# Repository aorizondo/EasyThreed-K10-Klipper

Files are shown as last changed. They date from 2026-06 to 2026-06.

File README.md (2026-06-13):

# Frankenprinter — K10 + CNC → impresora/CNC multifunción con Klipper

Proyecto de fusión de una impresora **EasyThreed K10** con un **CNC cartesiano casero**
(Arduino Uno + CNC Shield, motores NEMA17, mecánica reciclada de impresoras Epson de cinta)
para construir una máquina multifunción gobernada por **Klipper** desde una **Raspberry Pi**.

> Estado: **fase de documentación y experimentación**. Este repo es la base de conocimiento
> y las configuraciones de partida, no un producto terminado.

## Idea de partida (la tuya)

- Reutilizar el **cabezal de la K10** (hotend, termistor, cartucho calefactor, motor de
  extrusión, fan) porque mecánicamente la K10 es limitada.
- Usar la **mecánica del CNC** (guías más precisas, mejores motores NEMA17, mayor volumen
  ~280×280×70 mm) para los ejes **X, Y, Z**.
- **Klipper en ambos MCU**, sincronizados por la Pi en modo **multi-MCU**:
  - **MCU CNC** (Arduino Uno + CNC Shield) → ejes X/Y/Z + endstops + sonda Z.
  - **MCU K10** (placa GD32F303) → extrusor + calefactor + termistor + fan.
- Añadir sensores extra (sonda de eje Z, etc.).

## ⚠️ Lee esto primero

Hay un hallazgo de la investigación que **cambia el plan**: el USB-C de la K10 es **solo
alimentación** (no datos), y la placa **no tiene chip USB-serie**. Habilitar Klipper en la
K10 implica **soldar UART directamente al MCU** y **reversear el pinout** (nadie lo ha
publicado). Es factible pero es ingeniería inversa, no "soldar un USB".

👉 Lee **[docs/00-RESUMEN-EJECUTIVO.md](docs/00-RESUMEN-EJECUTIVO.md)** antes de comprar o
soldar nada. Incluye una **matriz de decisión** entre el camino ambicioso (fiel a tu idea) y
una alternativa pragmática de menor riesgo.

## Índice de documentación

| Doc | Contenido |
|-----|---|
| [00 Resumen ejecutivo](docs/00-RESUMEN-EJECUTIVO.md) | Hallazgos críticos y matriz de decisión de arquitectura |
| [01 Arquitectura](docs/01-arquitectura.md) | Modelo multi-MCU de Klipper, roles, flujo de datos |
| [02 Hardware K10](docs/02-hardware-k10.md) | MCU GD32F303, USB-PD, drivers HR4988, MOSFET, SWD |
| [03 Hardware CNC](docs/03-hardware-cnc.md) | Arduino Uno + CNC Shield V3, A4988/DRV8825, NEMA17, mecánica Epson |
| [04 Soldadura UART K10](docs/04-soldadura-uart-k10.md) | La realidad del "USB", dónde soldar, técnica SMD |
| [05 Flasheo Klipper](docs/05-flasheo-klipper.md) | Compilar/flashear en ATmega328P y en GD32F303 |
| [06 Cableado y pinout](docs/06-cableado-pines.md) | Tablas de pines, conexiones físicas |
| [07 Instalación host](docs/07-instalacion-host-pi.md) | Raspberry Pi, KIAUH, Moonraker, Mainsail |
| [08 Calibración](docs/08-calibracion.md) | rotation_distance, PID, extrusor, input shaping |
| [09 Sensores y sonda Z](docs/09-sensores-zprobe.md) | BLTouch, inductiva, microswitch, piezo; bed mesh |
| [10 Reversing pinout K10](docs/10-reversing-pinout-k10.md) | Metodología para mapear los pines del GD32 |
| [99 BOM, riesgos, troubleshooting](docs/99-bom-riesgos-troubleshooting.md) | Compras, errores comunes y soluciones |

## Estructura del repo

```
3dprinter/
├── README.md                  ← este archivo
├── docs/                      ← documentación técnica (orden de lectura por número)
├── klipper-config/            ← configs Klipper de partida
│   ├── printer.cfg            ← config principal (incluye los módulos)
│   ├── include/               ← módulos: MCUs, steppers, extrusor, sonda, macros
│   └── moonraker.conf         ← config de Moonraker
├── diagrams/                  ← diagramas de arquitectura y pinout (Mermaid/ASCII)
├── repos/                     ← repos clonados (referencia y código)
│   ├── klipper/               ← firmware + host
│   ├── moonraker/             ← API server
│   ├── kiauh/                 ← instalador
│   ├── klipper-drawbot/       ← REFERENCIA: Klipper en Arduino Uno + CNC Shield V3
│   ├── ECF-Marlin/            ← REFERENCIA: Marlin comunitario para EasyThreed
│   └── EasyThreeD-K9-STM32/   ← REFERENCIA: firmware K9
└── reference/                 ← notas y fuentes externas guardadas
```

## Fuentes clave

- Klipper: <https://www.klipper3d.org/> · repo <https://github.com/Klipper3d/klipper>
- Reversing de la placa K10 (fuente técnica más completa):
  <https://palmarci.me/blog/2025-05-02-easythreed-k10-3d-printer-main-board-reversing/index.html>
- Klipper en Arduino Uno + CNC Shield (referencia directa):
  <https://github.com/gwisp2/klipper-drawbot>
- Hackaday K9 (identificación de MCU):
  <https://hackaday.com/2024/02/12/easythreed-k9-the-value-in-a-e72-aliexpress-fdm-3d-printer/>

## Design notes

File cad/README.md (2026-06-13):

# CAD — Enclosures modulares (OpenSCAD)

Cajas paramétricas para las placas de la frankenprinter. Diseñadas para **imprimir en la K9**
(volumen 100×100×100 mm, boquilla 0.4, **PETG sin cama caliente**), con **tapa atornillada M3**,
**ventiladores de PC estándar** y **acople modular entre cajas**.

## Estado

| Pieza | Estado | Notas |
|---|---|---|
| Librería `lib/enclosure_lib.scad` | ✅ | Caja, bosses M3, repisa + postes de retención, ventilador PC, puertos, acople |
| `k10_enclosure.scad` | ✅ | PCB 79×53 (fotogrametría), retención por contorno, 3 sockets, ventana botones. Falta solo confirmar altura de componentes con calibre |
| `arduino_cnc_enclosure.scad` | ✅ | Footprint Uno estándar, standoffs en agujeros oficiales, ventilador 50mm en tapa, COMP_H=40 para shield+drivers |
| Acople entre cajas | ✅ | Atornillado lateral M3 (`couple_holes`), altura/posiciones comunes; ver `coupling_demo.scad` |

### Sockets / puertos por caja
- **K10**: motores (atrás), mazo cabezal VIN/FAN/HE/TH (derecha), microSD+USB-C+DC (frente), ventilador 40mm (izquierda), ventana de botones (suelo).
- **Arduino+Shield**: USB-B/jack (izquierda), cables motores (derecha), endstops (atrás), ventilador 50mm (tapa).

### Acople entre cajas
Agujeros M3 pasantes a **z=30 mm** y **y=±24 mm** (constantes `COUPLE_Z`/`COUPLE_YS` en la lib), en pared maciza de todas las cajas. Dos cajas contiguas se unen con **tornillo M3 + tuerca**. Es encadenable (cualquier caja con cualquiera). `coupling_demo.scad` verifica la alineación.

## Cómo generar

```bash
cd cad
./build.sh                 # genera stl/*.stl + renders/*.png de todas las piezas
```
O manualmente una pieza:
```bash
openscad -D 'part="body"' -o salida.stl k10_enclosure.scad           # STL imprimible
xvfb-run -a openscad -D 'part="assembly"' -o vista.png \
   --imgsize=1100,800 --camera=0,0,0,55,0,30,250 k10_enclosure.scad  # preview
```
`part` puede ser `body`, `lid` o `assembly`.

## Verificar imprimibilidad

```bash
python3 -c "import trimesh;m=trimesh.load('stl/k10_body.stl');print(m.extents, m.is_watertight)"
```
Debe dar las 3 dimensiones < 100 mm y `True` (estanco). El build avisa si alguna pieza no es 2-manifold.

## Parámetros que debes medir (TODO-MEDIR)

En `k10_enclosure.scad`, ajústalos con calibre antes de imprimir en serio:

- `PCB_L`, `PCB_W`, `PCB_T` — contorno y grosor de la placa K10.
- `COMP_H` — altura del componente más alto (define el alto interior).
- `HOLE_INSET` / `HOLE_DX` / `HOLE_DY` — posición de los agujeros de montaje del PCB.
- Posición/tamaño de los **puertos** (`port_rect(...)`): USB-C, jack DC, mazo del cabezal, microSD.
  Mídelos respecto al borde y a la altura sobre el PCB.

## Convenciones de diseño

- **Tornillería M3**: pasante 3.4, autorroscante 2.7, inserto térmico 4.2 (en `lib`, ajustables).
- **Holgura FDM** (`FIT`) 0.30 mm — sube/baja según tu calibración PETG.
- **Pared** 2.4 mm, **suelo/tapa** 2.0–2.4 mm.
- **PETG sin cama caliente**: el suelo es una superficie grande → **usa brim/orejas** en el slicer para
  evitar warping; bed limpio + laca/barra de pegamento. Evita corrientes de aire (la propia carcasa ayuda).
- **Ventiladores**: tamaños estándar 40/50/60/80/92/120 con su separación de tornillos en `fan_hole_spacing()`.
  Un **40 mm** sobra para refrigerar los drivers y cabe de sobra en estas cajas.

## Estructura

```
cad/
├── lib/enclosure_lib.scad   # librería paramétrica (la base de todo)
├── k10_enclosure.scad       # caja de la placa K10
├── build.sh                 # genera stl/ + renders/
├── renders/                 # previews PNG (versionados, referencia visual)
└── stl/                     # STL generados (NO versionados; regenerar con build.sh)
```

## Acople entre cajas

La librería incluye `dovetail_male()` / `dovetail_slot()` (cola de milano) para que las cajas se
acoplen lateralmente sin tornillos extra (más una fijación M3 opcional). Falta integrarlo en cada caja
eligiendo en qué caras va el macho y en cuáles la hembra — siguiente iteración.

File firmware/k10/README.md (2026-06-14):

# Firmware Klipper para la EasyThreed K10

Compilación **en la nube** (GitHub Actions) de Klipper para la placa K10, evitando
necesitar el toolchain ARM en local.

## MCU y parámetros (verificados)

| Dato | Valor |
|---|---|
| MCU | **GD32F303CBT6** — LQFP48, 128 KB flash, 48 KB RAM, Cortex-M4 |
| Target Klipper | `STM32F103` (+ *Disable SWD* para clones GigaDevice) |
| Cristal | 8 MHz externo |
| Comunicación | USB nativo en **PA11 (D−) / PA12 (D+)** + pull-up 1.5 kΩ externa en D+ |
| Bootloader SD | escribe en **0x08004000** (offset `0x4000` = 16 KiB) |
| Fichero que busca el bootloader | **`p10_printer.bin`** (NO `mksLite.bin`, eso es la K9) |
| Señal de éxito | el bootloader renombra el fichero a `p10_printer.CUR` |

La configuración fuente está en [`klipper.config`](klipper.config) (fragmento mínimo;
el CI lo expande con `make olddefconfig`).

## Cómo obtener el firmware

1. En GitHub: pestaña **Actions** → **Build K10 Klipper firmware** → **Run workflow**.
2. Al terminar, descarga el artefacto **`p10_printer`** (contiene `p10_printer.bin`).

## Cómo flashear (microSD)

> ⚠️ Sin SWD no hay rescate. No sabemos si el cargador valida checksum/cabecera propia.
> El renombrado a `.CUR` es la señal de que lo aceptó.

1. Copia `p10_printer.bin` a la **raíz** de una microSD en **FAT32**.
2. Con la placa apagada, inserta la SD; enciende y espera ~10–30 s.
3. Reinserta la SD en el PC:
   - Si ahora se llama **`p10_printer.CUR`** → aceptado y escrito. ✅
   - Si **sigue** como `.bin` → rechazado (posible checksum/cabecera) → haría falta SWD.
4. Conecta el USB (PA11/PA12) al PC. Solo ahora debe aparecer
   `/dev/serial/by-id/usb-Klipper_stm32f103xe_*`.

Detalle del cableado USB y la pull-up: [`../../diagrams/k10-soldadura-usb.md`](../../diagrams/k10-soldadura-usb.md).

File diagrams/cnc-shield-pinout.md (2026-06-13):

# Diagrama — CNC Shield V3 (Arduino Uno) → pines Klipper

Verificado contra el fuente de GRBL (`cpu_map_atmega328p.h`) y `repos/klipper-drawbot`.
Correspondencia Arduino→ATmega:  **D0–D7 = PD0–PD7** · **D8–D13 = PB0–PB5** · **A0–A5 = PC0–PC5**.

---

## Fotos de referencia (montaje real Arduino Uno + CNC Shield + drivers)

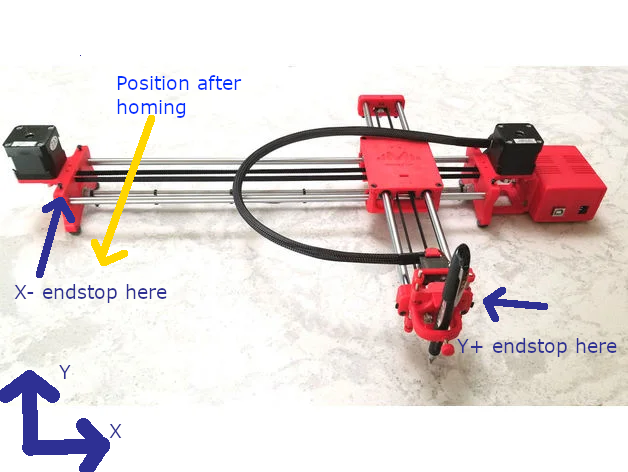
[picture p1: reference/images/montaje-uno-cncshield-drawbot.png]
Arduino Uno + CNC Shield V3 con drivers (montaje real, klipper-drawbot)


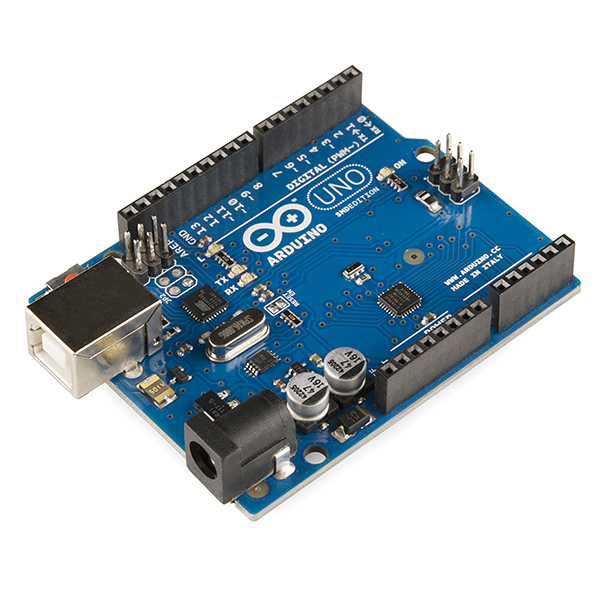
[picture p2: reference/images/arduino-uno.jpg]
Placa Arduino Uno R3


> Pinout gráfico oficial del CNC Shield V3 (no se puede incrustar por hotlink, ábrelo):
> Protoneer wiki <https://blog.protoneer.co.nz/arduino-cnc-shield/> ·
> Keyestudio <https://wiki.keyestudio.com/Ks0160_keyestudio_CNC_Shield_V3>

---

## Mapa de la shield (vista superior) — ASCII

```text
                        CNC SHIELD V3  (sobre Arduino Uno)
       +------------------------------------------------------------------+
       | ENABLE = D8 (PB0)  comun a los 4 drivers                         |
       |                                                                  |
       |   [ X ]        [ Y ]        [ Z ]        [ A ]                   |
       |   STEP = D2     STEP = D3    STEP = D4    (clon de X/Y/Z         |
       |   DIR  = D5     DIR  = D6    DIR  = D7     por jumpers, no usar) |
       |                                                                  |
       | Endstops:   X+ = D9 (PB1)    Y+ = D10 (PB2)    Z+ = D12 (PB4)    |
       | Spindle/servo: D11 (PB3, PWM HW)      SpinDir: D13 (PB5)         |
       | Abort A0 . Hold A1 . Resume A2 . Coolant A3                      |
       +------------------------------------------------------------------+
```

## Traducción a Klipper

```text
   stepper_x:   step=PD2   dir=PD5   enable=!PB0   endstop=^PB1
   stepper_y:   step=PD3   dir=PD6   enable=!PB0   endstop=^PB2
   stepper_z:   step=PD4   dir=PD7   enable=!PB0   endstop=^PB4   <-- PB4, no PB3
   (pin libre para sonda/servo: PB3 o PB5 si no usas spindle)
```

| Eje | STEP | DIR | ENABLE | ENDSTOP |
|-----|---|-----|---|---|
| X | PD2  | PD5 | !PB0 | ^PB1 (D9)  |
| Y | PD3  | PD6 | !PB0 | ^PB2 (D10) |
| Z | PD4  | PD7 | !PB0 | ^PB4 (D12) |

---

## Jumpers de microstepping (debajo de cada driver A4988/DRV8825)

```text
   MS1  MS2  MS3
    o    o    o     <- recomendado 1/16: los TRES jumpers PUESTOS (H H H en A4988)
                       NO uses 1/32 con el ATmega328P (riesgo "Timer too close").
```

| MS1 | MS2 | MS3 | A4988 | DRV8825 |
|-----|-----|-----|---|---|
| L | L | L | full  | full |
| H | H | H | 1/16  | 1/16 |
| L | L | H | 1/16  | 1/32 |

---

## Ajuste de corriente (Vref), medido con multímetro

```text
   A4988  (Rcs=0.1 ohm):   Vref = I_motor x 0.8     ej. 1.2 A -> 0.96 V
   DRV8825(Rcs=0.1 ohm):   Vref = I_motor / 2       ej. 1.2 A -> 0.60 V
   Mide entre el tornillo del potenciometro y GND. Apunta a ~70-85% de la I nominal del NEMA17.
```

## Aviso de ambiguedad del endstop Z

```text
   Shield V3 estandar (GRBL con VARIABLE_SPINDLE):  Z+ va a D12 = PB4.
   Si TU shield lleva Z+ a D11 -> seria PB3 (pero pierdes el pin PWM/servo).
   VERIFICA con multimetro a que pin del Arduino llega el header Z+/Z-.
```

Ref: [docs/03](../docs/03-hardware-cnc.md) ·
GRBL cpu_map <https://github.com/grbl/grbl/blob/master/grbl/cpu_map/cpu_map_atmega328p.h>

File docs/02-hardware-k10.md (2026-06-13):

# 02 — Hardware de la EasyThreed K10

Datos de ingeniería inversa publicada y de identificación de componentes. La fuente técnica más
completa es el reversing de palmarci.me; donde un dato no está verificado se indica.

Fuente principal: <https://palmarci.me/blog/2025-05-02-easythreed-k10-3d-printer-main-board-reversing/index.html>

---

## Microcontrolador

- **GigaDevice GD32F303RCT6**, núcleo ARM **Cortex-M4**.
- Encapsulado leído como **LQFP48** (nota: la referencia "RC" suele ser LQFP64/256 KB; posible
  discrepancia de lectura — verifícalo contando pines en tu placa).
- **Clon electrónico de STM32F103.** Para Klipper se compila como **STM32F103** y se trata como tal.
- Frecuencia/SRAM exactas de **esta** placa no confirmadas por la fuente (el GD32F303 de catálogo
  llega a 120 MHz). No son críticas para Klipper.

### Por qué importa
- **Klipper SÍ corre en GD32F303**, compilando con target STM32F103 + **bootloader de 28 KiB** y la
  opción *"Disable SWD at startup"*. Probado en miles de placas Creality 4.2.2.
  Ref: <https://klipper.discourse.group/t/installing-klipper-on-ender-3-4-2-2-board-and-gd32f303-chip/8165>

---

## Alimentación y "USB"

- Entrada por **DC barrel jack** + **USB-C**, con interruptor de 3 posiciones (OFF / USB-PD / DC).
- El **USB-C es SOLO alimentación**: controlador **PW6606 (USB-PD Sink)**. **No hay datos USB al MCU.**
- **No hay chip USB-serie** (CH340/CP2102). La operación de fábrica es **por microSD**.
- Hay una función USART0 en el firmware que **no se ejecuta**; los pines UART **no están ruteados** a
  ningún conector. → Para Klipper hay que **soldar UART al MCU** (ver [04](04-soldadura-uart-k10.md)).
- Tensión del sistema: el contexto apunta a **12 V** (no confirmado al 100% por la fuente). **Mídelo**
  antes de conectar nada: pon el multímetro en la entrada del barrel jack y en el riel principal.

> ⚠️ Antes de alimentar la K10 por DC mientras tienes el UART soldado y conectado a la Pi, asegúrate
> de **GND común** entre la K10 y la Pi/adaptador USB-TTL, y de **no** alimentar lógica de 5 V hacia
> pines de 3.3 V. El GD32 es de **3.3 V**: el adaptador USB-TTL debe ir en modo **3.3 V**, no 5 V.

---

## Drivers de motores

- **4× Heroic HR4988** (clon de A4988 con traductor integrado): X, Y, Z y extrusor.
- **Van soldados en la placa** (no son módulos extraíbles). No son TMC: **sin** StealthChop, **sin**
  UART, **sin** sensorless homing.
- En esta arquitectura solo usarás **el driver del extrusor** de la K10 (los de X/Y/Z los pone el
  CNC). Tendrás que localizar por reversing los pines step/dir/enable de **ese** driver.

---

## Calefactor y térmica

- MOSFET de potencia **Hooyi HY1403 (N-channel)** conmuta el cartucho calefactor del hotend.
  → El pin de **gate** de ese MOSFET es el `heater_pin` que buscas.
- **Termistor** NTC en divisor resistivo hacia un **pin ADC** del GD32 → ese es el `sensor_pin`.
  Tipo probable: NTC 100k. Verifica el `sensor_type` por calibración/medición (ver [08](08-calibracion.md)).
- Regulador **AMS1117** (genera el 3.3 V de la lógica).

---

## Depuración / flasheo (SWD)

Pines de debug accesibles (clave para reversing y para flashear Klipper sin bootloader SD):

| Señal | Pin GD32 |
|---|---|
| SWDIO | **PA13** |
| SWCLK | **PA14** |
| NRST  | **PB4**  |
| (JTAG extra) | PA15 / PB3 |

- En la unidad analizada la **RDP (read protection) estaba desactivada** → se puede volcar y reflashear.
- Puedes usar un **ST-Link V2** (~3€) o un **Raspberry Pi Pico como Picoprobe** + **OpenOCD**.
- Carga alternativa por **SD**: el bootloader MKS lee un `.bin` (la K10 carga `p10_printer.bin` a
  flash en offset `0x4000`, config en `k10_cfg.txt` offset `0x1F800`). Regla: el nombre del `.bin`
  debe acabar en `.bin` y **no** coincidir con el último flasheado, o el bootloader lo ignora.

---

## Firmware de fábrica

- **Marlin** (base 1.1.1 modificada por MKS, personalizada por EasyThreed). Las UIs EasyThreed están
  en Marlin mainline desde 2.0.9.3 (`MKS_ROBIN_LITE`).
- Para K10 se puede compilar Marlin con `BOARD_CREALITY_V422_GD32_MFL`.
- Proyecto comunitario Marlin para EasyThreed: **ECF-Marlin** (clonado en `repos/ECF-Marlin/`).
  Útil como **referencia de pinout** aunque sea para K7/K9.

---

## Lo que NO está publicado (lo tendrás que reversear tú)

- Pinout completo: qué pin del GD32 va a cada driver (step/dir/enable del extrusor), al gate del
  MOSFET del calefactor, al ADC del termistor, al fan y a los endstops.
- Metodología paso a paso en **[10 — Reversing del pinout K10](10-reversing-pinout-k10.md)**.

---

## Resumen para Klipper (Opción A)

| Recurso K10 | Uso en la frankenprinter | Pin Klipper |
|---|---|---|
| Driver extrusor (HR4988) | `[extruder]` step/dir/enable | `k10:P??` (reversing) |
| Gate MOSFET HY1403 | `[extruder] heater_pin` | `k10:P??` (reversing) |
| Divisor termistor → ADC | `[extruder] sensor_pin` | `k10:P??` (reversing) |
| Fan | `[fan]` / `[heater_fan]` | `k10:P??` (reversing) |
| UART soldado al MCU | enlace serie con la Pi | (define `serial:` en `[mcu k10]`) |

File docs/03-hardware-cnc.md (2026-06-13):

# 03 — Hardware del CNC (Arduino Uno + CNC Shield V3)

El CNC casero aporta la **mecánica** (ejes X/Y/Z) y el **MCU principal** de Klipper.

- Mecánica: cartesiana, piezas recicladas de impresoras Epson de cinta (correas timing, gargantas,
  deslizantes y carros). Dimensiones aprox. **280 × 280 × 70 mm** (X × Y × Z).
- Motores: **NEMA17** (paso 1.8° = 200 pasos/vuelta salvo que sean de 0.9°).
- Electrónica: **Arduino Uno (ATmega328P)** + **CNC Shield V3** con drivers **A4988/DRV8825**.
- Actualmente con **GRBL** → se reflashea a **Klipper**.

Referencia directa de este montaje exacto (Uno + CNC Shield V3 con Klipper):
`repos/klipper-drawbot/` y <https://github.com/gwisp2/klipper-drawbot>.

---

## Pinout CNC Shield V3 → nombres Klipper (VERIFICADO)

Correspondencia Arduino → puerto ATmega: **D0–D7 = PD0–PD7**, **D8–D13 = PB0–PB5**, **A0–A5 = PC0–PC5**.
Verificado contra el fuente de GRBL (`cpu_map_atmega328p.h`) y contra klipper-drawbot.

| Función | Pin Arduino | **Klipper** | Notas |
|---|---|---|---|
| X STEP | D2 | **PD2** | |
| Y STEP | D3 | **PD3** | |
| Z STEP | D4 | **PD4** | |
| X DIR | D5 | **PD5** | |
| Y DIR | D6 | **PD6** | |
| Z DIR | D7 | **PD7** | |
| ENABLE (común) | D8 | **!PB0** | activo-bajo (de ahí el `!`); deshabilita los 4 drivers a la vez |
| X endstop | D9 | **PB1** | usar `^PB1` (pull-up) |
| Y endstop | D10 | **PB2** | usar `^PB2` |
| Z endstop | **D12** | **PB4** | ver nota ⚠️ |
| Spindle Enable/PWM | D11 | PB3 | PWM por hardware; en drawbot lo usan para servo |
| Spindle Dir | D13 | PB5 | LED integrado del Uno |
| Coolant | A3 | PC3 | |
| Abort / Hold / Resume | A0 / A1 / A2 | PC0 / PC1 / PC2 | botones GRBL, no se usan en Klipper |

### ⚠️ Endstop Z = PB4 (D12), no PB3
La CNC Shield V3, compilada con `VARIABLE_SPINDLE` (el **default** de GRBL 0.9/1.1), mueve el PWM de
spindle a **D11 (PB3)** y por eso el **Z-limit queda en D12 (PB4)**. klipper-drawbot usa exactamente
`endstop_pin: ^PB4` para Z. **Verifícalo con multímetro**: comprueba a qué pin del Arduino llega el
header "Z+/Z−" de tu shield. Si en tu placa concreta Z va a D11, sería PB3 (pero entonces pierdes el
pin de servo/PWM). Recomendado: **cablea Z a D12 = PB4**.

### El "4º eje" (A) de la shield
En la CNC Shield V3 el slot **A** se **clona** de X/Y/Z por jumpers (no tiene pines step/dir propios
libres). No lo uses como eje independiente sin cablear a mano sacrificando otra función. Para esta
frankenprinter **no hace falta**: el extrusor lo mueve la K10, no la shield.

---

## Drivers A4988 / DRV8825

### Microstepping (jumpers MS1/MS2/MS3 bajo cada driver)
| MS1 | MS2 | MS3 | A4988 | DRV8825 |
|---|---|---|---|---|
| L | L | L | full | full |
| H | L | L | 1/2 | 1/2 |
| L | H | L | 1/4 | 1/4 |
| H | H | L | 1/8 | 1/8 |
| H | H | H | 1/16 | 1/16 |
| L | L | H | 1/16 | 1/32 |

**Recomendado: 1/16** (los 3 jumpers puestos en A4988). No subas a 1/32 con el ATmega328P: el límite
de step rate del AVR puede provocar `Timer too close`. En Klipper pon `microsteps: 16`.

### Corriente (Vref) — mide con el driver montado y alimentado
- **A4988** (Rcs=0.1Ω): `Vref = I_motor × 0.8`. Ej.: 1.2 A → 0.96 V. Ajusta a ~70–85 % de la nominal del motor.
- **DRV8825** (Rcs=0.1Ω): `Vref = I_motor / 2`. Ej.: 1.2 A → 0.6 V.
- Ojo con el resistor de sensado del módulo: "R100"=0.1Ω, "R050"=0.05Ω, "R200"=0.2Ω → cambia la fórmula.
- Mide Vref entre el **tornillo del potenciómetro** y **GND**. Empieza bajo y sube si pierde pasos; si
  el motor o el driver queman, baja.

---

## rotation_distance (cómo lo calcula Klipper)

Klipper **no usa steps/mm**; usa `rotation_distance` = mm que avanza el eje por **una vuelta** del motor.

```
rotation_distance = full_steps_per_rotation × microsteps / (steps_per_mm)
pasos/mm = (200 × microsteps) / rotation_distance         # 200 para NEMA17 1.8°
```

- **Correa GT2 (paso 2 mm) + polea N dientes:** `rotation_distance = 2 × N`. (20T → 40; 16T → 32.)
- **Husillo:** `rotation_distance = paso efectivo` (M5 → 0.8; T8 1 entrada → 2; T8 4 entradas → 8).

### Mecánica Epson reciclada: calíbrala, no la adivines
Las correas/poleas de impresoras Epson **no son estándar** (paso y nº de dientes inciertos). Pon un
valor de partida (p.ej. 40) y **calíbralo midiendo** con el procedimiento de "mover y medir" de
[08 — Calibración](08-calibracion.md). Para Z con husillo recuperado, mismo método en vertical con calibre.

> Pista: muchas correas de carro de Epson son de paso 2 mm; las poleas suelen rondar 16–22 dientes.
> Arranca con `rotation_distance: 40` en X/Y y ajusta tras medir 100–200 mm reales.

---

## Conexión al host

- **Uno genuino** (chip USB ATmega16U2) → `/dev/ttyACM0`.
- **Clon** (CH340) → `/dev/ttyUSB0`.
- Usa siempre el ID estable: `ls /dev/serial/by-id/*` y pon esa ruta en `serial:` del `[mcu]`.
- Si tienes varios CH340 sin serie única, usa `ls /dev/serial/by-path/*` y enchufa siempre en el mismo puerto.

---

## Límites reales del ATmega328P como MCU Klipper

- **Flash 32 KB**: justa → desactiva features en `make menuconfig` para que quepa.
- **RAM 2 KB**: ok para 3 ejes + endstops; no para muchos extras.
- **Step rate**: ~157k pasos/s con 1 stepper, **~99k con 3 simultáneos** (~33k/eje). Con 80 pasos/mm
  son ~410 mm/s teóricos por eje — de sobra para tu mecánica. Si aparece `Timer too close`: baja
  microsteps, velocidad o aceleración.
- **Una sola UART**, sin CAN. ENABLE compartido (no puedes deshabilitar ejes por separado).

Fuentes: <https://www.klipper3d.org/Benchmarks.html> ·
`repos/klipper-drawbot/README.md` ·
GRBL cpu_map: <https://github.com/grbl/grbl/blob/master/grbl/cpu_map/cpu_map_atmega328p.h>

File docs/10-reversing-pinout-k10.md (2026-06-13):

# 10 — Metodología para reversear el pinout de la K10

Esta es **la parte más dura** de la Opción A: nadie ha publicado qué pin del GD32F303 va a cada
actuador de la K10. Necesitas mapear, como mínimo:

- Driver del **extrusor** (HR4988): STEP, DIR, ENABLE.
- **Calefactor**: gate del MOSFET HY1403 (`heater_pin`).
- **Termistor**: pin ADC del divisor (`sensor_pin`).
- **Fan**: salida controlable.
- (Opcional) endstops, si quisieras usarlos — pero en esta arquitectura los pones en el CNC.

Tienes tres vías complementarias; combínalas. La 1 es la más rápida si funciona.

---

## Vía 1 — Extraer el pinout del firmware (la más eficiente)

El firmware de fábrica es **Marlin**, y Marlin define todos los pines en un archivo de placa. Si
identificas la placa Marlin que usa la K10, tienes el mapa casi regalado.

1. **Vuelca el firmware** de la K10 por SWD (RDP estaba desactivado en la unidad analizada):
   ```bash
   openocd -f interface/stlink.cfg -f target/stm32f1x.cfg \
           -c "init; reset halt; dump_image k10_original.bin 0x08000000 0x40000; exit"
   ```
   Guárdalo en `reference/`.
2. La K10 compila Marlin con un board tipo `BOARD_CREALITY_V422_GD32_MFL` (Creality 4.2.2 GD32). Abre
   el pins file correspondiente de Marlin y compáralo:
   - En `repos/ECF-Marlin/` (Marlin comunitario EasyThreed) busca los `pins_*.h` de la familia.
   - En Marlin mainline: `Marlin/src/pins/stm32f1/pins_CREALITY_V422.h` y la variante GD32.
   - Busca `HEATER_0_PIN`, `TEMP_0_PIN`, `E0_STEP_PIN`, `E0_DIR_PIN`, `E0_ENABLE_PIN`, `FAN_PIN`,
     `X/Y/Z` endstops.
3. **Traduce** los nombres Marlin (p.ej. `PB0`, `PA1`) directamente a Klipper (mismos nombres `Pxx`).
   ⚠️ Aviso: que la K10 sea "tipo 4.2.2" no garantiza pinout idéntico — EasyThreed pudo recablear. Por
   eso **verifica** cada pin con la Vía 2 antes de aplicar potencia.

> El blog de reversing (palmarci) ya confirma componentes (HR4988, MOSFET HY1403, AMS1117) y los pines
> SWD; úsalo como ancla. URL en [02](02-hardware-k10.md).

---

## Vía 2 — Trazado físico con multímetro (verificación, placa SIN alimentar)

Continuidad (modo pitido) entre el **pin del chip** y el **componente**:

- **Calefactor (`heater_pin`)**: localiza el MOSFET HY1403. Su **gate** va, normalmente vía una resistencia
  de puerta, a un pin del GD32. Pita entre cada pin candidato del MCU y el gate → ese es el `heater_pin`.
  (Source a GND, drain al conector del calefactor.)
- **Termistor (`sensor_pin`)**: localiza el conector del termistor y el divisor (una resistencia ~4.7k a
  3.3 V + el termistor a GND, nodo medio al ADC). Pita del nodo medio a un pin ADC del GD32 (PA0–PA7,
  PB0/PB1, PC0–PC5). Ese es el `sensor_pin`.
- **Driver extrusor (STEP/DIR/EN)**: identifica el HR4988 del extrusor. Sus pines STEP, DIR, ENABLE
  (según datasheet A4988/HR4988) se trazan a pines del GD32. Pita cada uno.
- **Fan**: igual que el calefactor pero el MOSFET/transistor del ventilador.

Anota todo en una tabla (plantilla abajo). Usa la datasheet del HR4988/A4988 para saber qué patilla es
STEP/DIR/EN, y un mapa de pines del GD32F303 LQFP para numerar patillas.

---

## Vía 3 — Sondeo dinámico con Klipper (confirmación final, con cuidado)

Una vez tengas Klipper en la K10 y candidatos del firmware/multímetro, **confirma** sin mecánica ni
calefactor conectados de potencia:

- **Salidas digitales** (heater gate, fan, enable): define un `[output_pin test]` temporal y conmútalo
  con `SET_PIN PIN=test VALUE=1/0` mientras mides con multímetro/LED en la salida. Verás qué conector se activa.
- **ADC (termistor)**: define el `[extruder] sensor_pin` candidato con `sensor_type: Generic 3950` y mira
  si lee temperatura ambiente coherente. Si lee 0 o max → pin equivocado.
- **STEP/DIR del extrusor**: con `STEPPER_BUZZ` (con el motor conectado pero el hotend frío y
  `min_extrude_temp` puenteado solo para test de movimiento — o usa un `[manual_stepper]` temporal).

> ⚠️ Haz el sondeo dinámico **con el calefactor de potencia desconectado** hasta confirmar el `heater_pin`.
> Activar por error un pin que no es el del MOSFET no rompe nada, pero activar el calefactor sin termistor
> validado sí es peligroso (térmica descontrolada). Klipper protege con `min_temp/max_temp`, pero valida
> el termistor **antes** de permitir calentar.

---

## Plantilla de mapa de pines (rellénala)

Copia esto a `reference/k10-pinmap.md` y ve completándolo:

```
# Mapa de pines K10 (GD32F303) — VERIFICAR cada uno antes de aplicar potencia

UART (comms host):   TX=PA9   RX=PA10   GND=___   [Vía: soldado, ver doc 04]

Extrusor STEP:   P____   [firmware:___ | multímetro:OK/NO | klipper:OK/NO]
Extrusor DIR:    P____   [ ... ]
Extrusor ENABLE: P____   (activo-bajo? sí/no -> usar ! )
Calefactor (heater_pin): P____   [gate MOSFET HY1403]
Termistor (sensor_pin):  P____   [ADC; sensor_type probado: __________]
Fan capa:        P____
Fan hotend:      P____   (si existe; o conéctalo a heater_fan)

Endstops (si se usaran en K10, NO recomendado): X=__ Y=__ Z=__
SWD: SWDIO=PA13  SWCLK=PA14  NRST=PB4   (confirmados por reversing publicado)
```

---

## Resultado

Cuando el mapa esté completo y verificado, traslada los valores a
`klipper-config/include/extruder-hotend.cfg` (reemplaza los `P??`). A partir de ahí, calibra térmica y
extrusor según [08](08-calibracion.md).

Si en algún punto te bloqueas (pin que no aparece, chip difícil de trazar), recuerda la salida de bajo
riesgo: **Opción B** ([00](00-RESUMEN-EJECUTIVO.md)) — un board barato con pinout conocido para el cabezal,
reutilizando el hotend/motor de la K10 como piezas.

Fuentes: reversing K10 <https://palmarci.me/blog/2025-05-02-easythreed-k10-3d-printer-main-board-reversing/index.html> ·
Marlin pins <https://github.com/MarlinFirmware/Marlin/tree/2.1.x/Marlin/src/pins/stm32f1> ·
`repos/ECF-Marlin/`

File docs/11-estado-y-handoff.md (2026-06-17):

# 11 · Estado del proyecto y handoff

> Documento vivo del **progreso real** (los docs 00–10 son el plan/diseño). Última actualización: 2026-06-16.
> Pensado para retomar el proyecto en una sesión limpia.

## Resumen en una línea

Frankenprinter: fusionar el **cabezal de una EasyThreed K10** + la **mecánica de un CNC casero**
(Arduino Uno + CNC Shield V3) bajo **Klipper multi-MCU** desde una Raspberry Pi. Repo público:
<https://github.com/aorizondo/EasyThreed-K10-Klipper>.

## Hardware confirmado (con correcciones al plan original)

| Componente | Dato confirmado |
|---|---|
| MCU K10 | **GD32F303CBT6** — LQFP48, **128 KB** flash, 48 KB RAM, Cortex-M4 (no el RCT6/64 que citaba palmarci) |
| Comunicación K10 | **USB nativo** PA11(D-)/PA12(D+) + pull-up 1.5 kΩ a 3.3 V soldada. Cristal 8 MHz |
| MCU CNC | **Arduino Uno R3 oficial** (2341:0043, ATmega16U2), ATmega328P @16 MHz |
| Drivers CNC | **4× A4988** (PCB roja "HW-134"), microstepping **1/16** (3 jumpers bajo cada driver) |
| Motores X/Y | Reciclados de impresoras **Epson LX** (pasos/correa a calibrar) |
| Motor 2º en Y | El eje Y tiene **2 motores** (pórtico). Socket A del shield, clonado de Y |
| Eje Z | Tornillo (≈ **M8**, paso por confirmar — probable varilla roscada 1.25 mm) |
| Área de trabajo | **380 × 360 mm** (X/Y) · **recorrido Z 40 mm** |
| Endstops | **Ninguno** en ningún eje → homing manual (cero a mano antes de cada trabajo) |

## Hitos conseguidos ✅

1. **K10 con Klipper por USB — FUNCIONANDO y validado.**
   - Compilado en GitHub Actions (`.github/workflows/build-k10-klipper.yml`), flasheado por microSD
     (`p10_printer.bin` → bootloader lo acepta y renombra a `.CUR`, offset 0x4000).
   - Enumera `1d50:614e`, comunica (console.py, get_uptime ok). CLOCK_FREQ=72 MHz.
   - `by-id`: `usb-Klipper_stm32f103xe_30303B4D1C20300836303638-if00`.
   - Config: [`firmware/k10/klipper.config`](../firmware/k10/klipper.config).
2. **Arduino (CNC) con Klipper — flasheado y validado** (con `HARD_PWM`). 14 KB/32 KB.
   - `by-id`: `usb-Arduino__www.arduino.cc__0043_7573530303135180C070-if00`. Serial 250000.
   - Config: [`firmware/cnc/klipper.config`](../firmware/cnc/klipper.config).
3. **Firmware OEM de fábrica de la K10 — respaldado** (billete de vuelta a fábrica).
   - Fuente: palmarci. `firmware/k10/stock/` (gitignorado, propietario) + README con hashes.
4. **Reversing del firmware OEM** ([`firmware/k10/reversing.md`](../firmware/k10/reversing.md)):
   - Steps/mm K10: X606 Y606 Z600 E1040; PID hotend Kp22.2/Ki1.08/Kd114; botones S3–S9.
   - Mapa de pines (38 agentes): PA2=termistor, PA3=endstop, PA5/6/7=SPI, teclado en PB*,
     PWM PB4/5/6/7/8. **Sin resolver: pin del HEATER** (soft-PWM vía tabla RAM) y eje de cada stepper.

## Decisiones de arquitectura

- **Reparto multi-MCU**: Arduino = movimiento X/Y/Z + endstops; K10 = cabezal (heater, fan, termistor,
  extrusor E). Pi = Klippy.
- **Doble motor Y en Klipper**: Opción B (software) → `[stepper_y]` + `[stepper_y1]` (socket A = D12/D13),
  sin auto-cuadrado (no hay endstops). Requiere quitar los jumpers de clonado del shield.
- **Sin endstops** → homing manual: `[force_move] enable_force_move: True` + macro `G28` con
  `SET_KINEMATIC_POSITION X=0 Y=0 Z=0`. (A4988 no soportan sensorless.)
- **PWM spindle/láser**: como D12/D13 se usan para el 2º motor Y, el PWM iría a D9/D10/D11 (libres al no
  haber endstops; son PWM HW del 328p).

## Próximos pasos para RETOMAR la vía Klipper

1. Confirmar con **multímetro** en la placa K10 real: pin del **heater**, pin del **termistor** (¿PA2?),
   y **qué eje es cada stepper** (el reversing no lo fija; además el binario es de otra variante de placa).
2. Calibrar **steps/mm** reales del CNC (motores Epson LX + tornillo Z) — ver más abajo.
3. Montar `printer.cfg` multi-MCU (lado CNC ya definido; lado K10 tras el multímetro).
4. Ajustar **Vref** de cada A4988 al energizar los NEMA/Epson.
5. Instalar host Klipper + Moonraker en la Pi (KIAUH).

## Estado actual: GIRO TEMPORAL A GRBL

El usuario vuelve **temporalmente a GRBL** en el Arduino+Shield para tener el CNC operativo como antes
(la vía Klipper queda documentada aquí para retomarla). Para GRBL:
- Los **jumpers de clonado del eje A se han vuelto a poner en Y** (modo espejo HW para el 2º motor Y).
- GRBL estándar (gnea/grbl 1.1) ve 3 ejes; el 2º motor Y lo mueve el hardware clonado. Pendiente:
  clonar/compilar/flashear GRBL (bloqueado por red en esta sesión) + configurar `$$` (ver plan GRBL).

## Punteros rápidos

- Toolchains locales: `avr-gcc`+`avrdude` (AVR) sí; `arm-none-eabi-gcc` NO (la K10 se compila por CI).
- venv para `console.py`: `repos/klipper/.venv-klippy` (Python 3.12 + pyserial/greenlet/cffi).
- Validar un MCU: `repos/klipper/.venv-klippy/bin/python repos/klipper/klippy/console.py [-b 250000] <dev>`.

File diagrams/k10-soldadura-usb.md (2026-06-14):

# Esquema de soldadura — USB nativo del GD32 (K10)

Opción **preferida** para comunicar la K10 con Klipper: usar el **USB nativo del GD32F303**
(PA11 = D−, PA12 = D+) llevándolo a un puerto/cable USB, con la **pull-up de 1.5 kΩ obligatoria
en D+**. La K10 aparecerá directamente como dispositivo Klipper (`/dev/serial/by-id/usb-Klipper_...`),
sin adaptador ni GPIO.

> Fuentes: Klipper sobre STM32F103 por USB
> <https://klipper.discourse.group/t/klipper-support-on-stm32f103-over-usb/25074> ·
> GD32F303 (Creality 4.2.2) <https://klipper.discourse.group/t/support-for-new-creality-boards-4-2-2-with-gd32f303/3016> ·
> El STM32F103/GD32F303 **no** trae pull-up interna en D+ → hay que añadirla externa.

---

## 1. Esquema eléctrico

```text
                     3.3 V
                       |
                  +----+----+
                  |  1.5 kΩ |   (pull-up OBLIGATORIA en D+; sin ella el USB NO enumera)
                  +----+----+
                       |
   GD32F303            |  nodo D+
   (placa K10)         |
   PA12  (USB D+) o----+--------------->  D+   (verde)   ----.
                                                              |
   PA11  (USB D-) o--------------------->  D-   (blanco)  ----+---> cable USB a la Raspberry Pi
                                                              |
   GND            o--------------------->  GND  (negro)   ----'
                                          VBUS +5V (rojo) = NO conectar al MCU
```

Notas eléctricas:
- **3.3 V para la pull-up**: tómalo del riel de 3.3 V de la placa (salida del **AMS1117**) o de un pin
  **VDD** del GD32. NO de 5 V.
- **VBUS (+5V, hilo rojo del USB): NO se conecta** al MCU. La K10 se alimenta por su propia DC; el USB
  solo aporta datos + masa.
- **GND común**: el hilo negro del USB une la masa de la K10 con la de la Pi (imprescindible).
- **D+ y D− cortos y trenzados** entre sí (son señal diferencial a 12 Mbit/s). Cuanto más cortos, mejor.
- Opcional pero recomendable: **22 Ω en serie** en cada línea D+/D− cerca del MCU (mejora integridad de
  señal). No es imprescindible para tramos cortos; la de **1.5 kΩ en D+ sí lo es**.

---

## 2. Localizar PA11 / PA12 en el chip

El reversing confirmó **SWDIO = PA13** y **SWCLK = PA14**. Usa SWDIO como referencia: los pines de USB
están justo al lado. Esta secuencia del borde es igual en LQFP48 y LQFP64 (solo cambia la numeración).

```text
   borde del GD32 (LQFP) — misma secuencia en 48 y 64 pines:
  +---++----++----++----++-----++---++---++-----++----+
   PA9  PA10  PA11  PA12   PA13  VSS  VDD   PA14  PA15 
  +---++----++----++----++-----++---++---++-----++----+
               D-    D+   SWDIO            SWCLK       

   Desde SWDIO (PA13), hacia el lado opuesto a VSS/VDD:
   PA13(SWDIO) -> PA12(D+) -> PA11(D-) -> PA10 -> PA9
```

Verifica SIEMPRE con multímetro (continuidad) antes de soldar: PA13 debe dar continuidad con el pad de
SWDIO que ya identificaste en el reversing; el contiguo es PA12 (D+).

> ⚠️ **Sobre la marca redonda (punto) del MCU:** ese punto marca el **pin 1 (VBAT)** y está en la
> esquina **DIAGONALMENTE OPUESTA** a PA11/PA12. Es normal que NO coincida con los pines que vas a
> soldar: D+/D− están en el lado contrario al punto. No es un error.
>
> En tu foto (punto arriba-izquierda, cristal a la izquierda) los pines de USB están en el **borde
> DERECHO**. Contando desde la esquina superior-derecha hacia abajo:
> **1 = VDD, 2 = VSS, 3 = PA13 (SWDIO), 4 = PA12 (D+), 5 = PA11 (D−).**

### Fotos de referencia
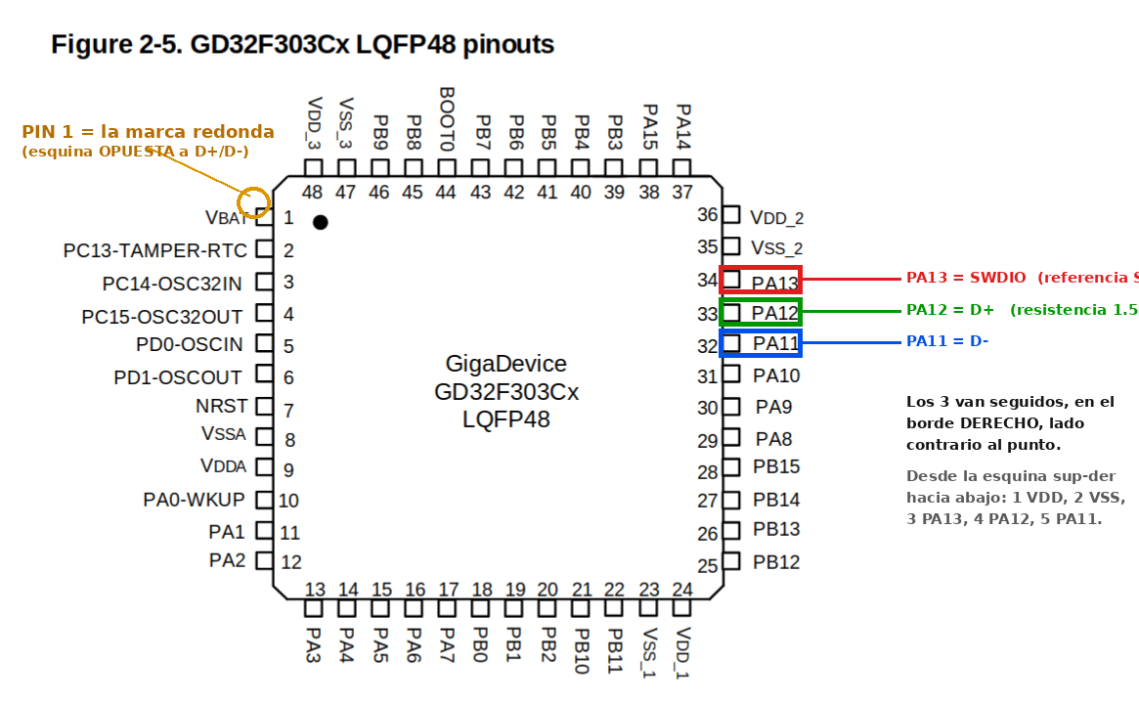
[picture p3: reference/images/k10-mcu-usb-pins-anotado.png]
Pines de USB anotados sobre el pinout: punto = pin 1 (esquina opuesta), PA13/PA12/PA11 en el borde derecho


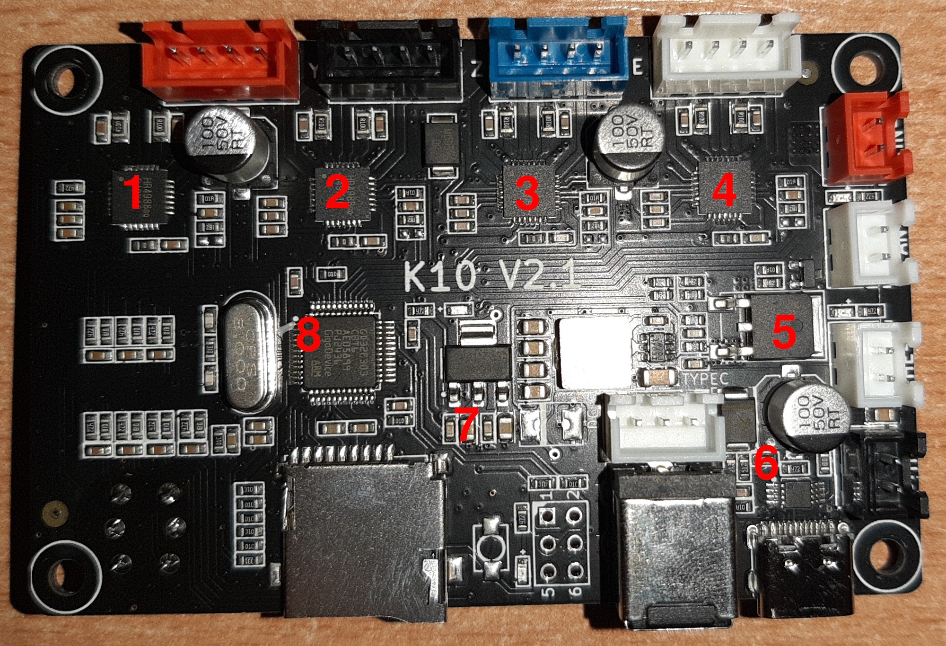
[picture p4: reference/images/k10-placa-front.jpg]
Cara de componentes de la K10 (MCU GD32 en el centro)


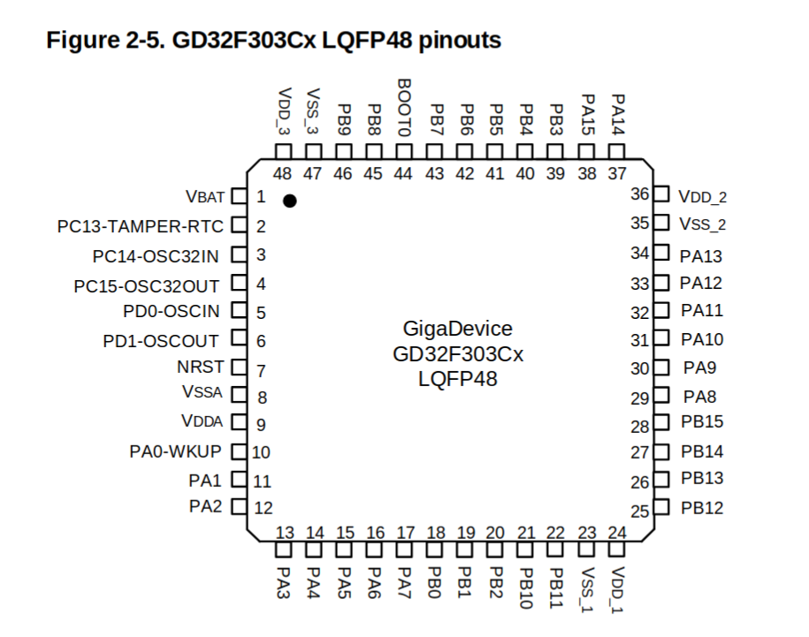
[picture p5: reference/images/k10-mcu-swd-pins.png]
Pines de depuración/SWD del GD32 identificados en el reversing


---

## 3. Colores estándar de un cable USB-A (al cortarlo)

| Hilo | Señal | Conecta a |
|---|---|---|
| Rojo  | VBUS +5V | **NO conectar** (la K10 se autoalimenta) |
| Blanco| D− | PA11 del GD32 |
| Verde | D+ | PA12 del GD32 (+ pull-up 1.5 kΩ a 3.3 V) |
| Negro | GND | GND de la K10 (masa común) |

> Si el cable no respeta colores, identifícalos con multímetro contra un conector USB-A conocido
> (pin 1=VBUS, 2=D−, 3=D+, 4=GND).

---

## 4. Procedimiento de soldadura

1. **Placa sin alimentar.** Pulsera antiestática.
2. Localiza y **verifica** PA12 (D+) y PA11 (D−) con multímetro (sección 2).
3. Suelda la **pull-up de 1.5 kΩ** entre PA12 (D+) y el riel de 3.3 V (salida AMS1117 o VDD). Es el
   punto crítico.
4. Suelda hilos finos (AWG30) a PA12 (D+) y PA11 (D−), **cortos y trenzados** entre sí.
5. Suelda GND a un punto de masa cómodo.
6. Conecta esos hilos a los del cable USB: verde→D+, blanco→D−, negro→GND. **Rojo (VBUS) aislado.**
7. Fija todo con kapton/pegamento (alivio de tensión).
8. Enchufa el USB a la Pi y alimenta la K10 por su DC.
9. En la Pi: `ls /dev/serial/by-id/*` → debe aparecer `usb-Klipper_stm32f103xe_...` (tras flashear Klipper).

---

## 5. Klipper para esta opción (menuconfig)

```text
Micro-controller Architecture: STMicroelectronics STM32
Processor model: STM32F103
Bootloader offset: 16KiB bootloader     (K10: el cargador escribe en 0x4000 = 16 KiB; "No bootloader" si flasheas por SWD)
Communication interface: USB (on PA11/PA12)      <-- ESTA es la clave de la opción USB nativo
[*] Disable SWD at startup (GD32)
```

Tras `make`, flashea por SWD o SD (ver [docs/05](../docs/05-flasheo-klipper.md)). En `[mcu k10]`:
`serial: /dev/serial/by-id/usb-Klipper_stm32f103xe_XXXX-if00`.

> ⚠️ **Importante — el USB nativo NO enumera hasta que Klipper esté flasheado.** El periférico USB del
> GD32 lo activa el *firmware*; no es un chip USB-serie autónomo (CH340/FT232). Con el firmware de
> fábrica (EasyThreed), conectar el cable a la PC no produce **nada** (ni "dispositivo desconocido").
> Por eso el **primer** flasheo debe ir por **SWD o microSD**, nunca por USB. Solo después de tener
> Klipper dentro aparecerá `/dev/serial/by-id/usb-Klipper_...` y servirá para validar esta soldadura.

---

## 6. Flasheo por microSD (datos reales del bootloader de la K10)

> Fuente: reversing de la placa K10 (palmarci)
> <https://palmarci.me/blog/2025-05-02-easythreed-k10-3d-printer-main-board-reversing/index.html>

La K10 **NO** usa el bootloader MKS de la K9. No busca `mksLite.bin`. Su cargador propio busca:

| Dato | Valor en la K10 |
|---|---|
| MCU | **GD32F303CBT6** (Cortex-M4, **LQFP48**, 128 KB flash, 48 KB RAM) — confirmado por el marcado del chip; el reversing de palmarci citaba un RCT6/LQFP64, pero esta placa monta el CBT6 de 48 pines |
| Fichero de firmware que busca en la raíz de la SD | **`p10_printer.bin`** |
| Offset de escritura | **`0x4000` = 16 KiB** (→ menuconfig: *16KiB bootloader*) |
| Fichero de config opcional | `k10_cfg.txt` (se almacena en `0x1F800`) |
| Tras flasheo correcto | renombra el `.bin` a `.CUR` |

Procedimiento:

1. **Respalda primero el firmware de fábrica** (por SWD, leyendo la flash) y guárdalo. Plan de
   recuperación imprescindible por si el `.bin` de Klipper no bootea.
2. Compila Klipper con el menuconfig de la sección 5 (**offset 16KiB**).
3. Copia `out/klipper.bin` a la **raíz** de una microSD (FAT32) **renombrado a `p10_printer.bin`**.
4. Con la placa apagada, inserta la SD; enciende y espera ~10-30 s.
5. Reinserta la SD en la PC: si el fichero ahora se llama `p10_printer.CUR`, el cargador lo aceptó y
   escribió. Si **sigue** llamándose `.bin`, fue **rechazado** (posible checksum/header propio del
   cargador) → habrá que flashear por SWD.

> ⚠️ **Sin confirmar:** no sabemos si el cargador de la K10 valida checksum/cabecera o desencripta el
> `.bin` (muchos cargadores tipo MKS sí lo hacen). Por eso el paso 1 (respaldo + SWD de rescate) no es
> opcional. La señal de éxito/rechazo es el renombrado a `.CUR` del paso 5.

---

## Comparativa rápida con las otras vías

| Vía | Soldadura | Compras | Resultado |
|---|---|---|---|
| **A. USB nativo** | PA11/PA12 + R 1.5 kΩ + cable USB | nada (cable USB) | `/dev/serial/by-id/usb-Klipper_...` |
| B. UART por GPIO Pi | PA9/PA10/GND a GPIO de la Pi | nada | `/dev/ttyAMA0` |
| C. UART + USB-TTL | PA9/PA10/GND al adaptador | adaptador 3.3 V | `/dev/serial/by-id/...` |

Las tres valen. La **A** es la más "limpia" (USB de verdad) y es la que sugeriste; su único extra es la
resistencia de 1.5 kΩ. Si soldar D+/D− finos te incomoda, la **B** (UART al GPIO de la Pi) es el plan B
sin comprar nada. Ver [k10-uart-conexion.md](k10-uart-conexion.md).

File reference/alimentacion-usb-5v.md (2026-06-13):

# Alimentar el MCU de la K10 por un USB independiente (5V) con protección

Objetivo: un **puerto USB separado** (no el USB-C PD de fábrica) que alimente **solo la lógica
del MCU** (3.3V) y, opcionalmente, lleve los datos de Klipper (D+/D-). Los motores y el
calefactor siguen necesitando 12V aparte; el USB **no** los alimenta.

## Dónde inyectar los 5V: la entrada del AMS1117 (VIN)

La K10 genera su 3.3V con el regulador **AMS1117-3.3** (12V → buck → ~5V → AMS1117 → 3.3V → MCU).
Para alimentar la lógica con 5V del USB, se inyecta en la **entrada del AMS1117 (pin VIN)**, que es
el carril de ~5V. **No** se toca el USB-C PD ni los pads "DC PWR/TYPEC PWR" (esos son de 12V).

### Identificar el pin VIN del AMS1117 (encapsulado SOT-223, 3 patillas + lengüeta)
| Patilla | Función | Cómo reconocerla |
|---|---|---|
| Lengüeta grande + patilla central | **VOUT = 3.3V** | mide 3.3V a masa con la placa encendida → NO soldar aquí |
| Una patilla lateral | **GND** | mide 0V |
| La otra patilla lateral | **VIN** (entrada) | mide ~5V (o ~12V si va directo) → **AQUÍ van los 5V+** |

> Con la placa alimentada normalmente, mide cada patilla a masa con el multímetro: la de 3.3V es la
> salida (no tocar), la de 0V es GND, y la restante es **VIN** (ahí soldar el 5V+ del USB).
> El AMS1117 tolera de ~4.5V a ~15V en VIN, así que 5V es seguro.

## Protección recomendada (tu pregunta de seguridad) — SÍ, es posible y aconsejable

El **AMS1117 ya es el regulador** que protege la lógica (salida 3.3V estable). Lo que hay que
proteger es la **entrada de 5V**. Cadena recomendada, sencilla y robusta:

```text
  USB 5V+ ──[ Polyfuse 500mA ]──►|──────┬──────────────►  AMS1117 VIN  ──►(regula a 3.3V → MCU)
                              Schottky   │
                              (SS14 /    ├─[ TVS 5.6V ]─┐   (opcional, anti-picos/ESD)
                               1N5819)   ├─[ 10µF ]─────┤   (estabiliza la entrada)
                                         │              │
  USB GND ───────────────────────────────┴──────────────┴──────────────►  GND de la placa
```

- **Polyfuse (PTC) 500 mA**: rearmable; protege contra **cortocircuito / sobrecorriente**.
- **Diodo Schottky (SS14 o 1N5819)**, cátodo hacia la placa: **anti-polaridad inversa** y evita
  retroalimentar si algún día también conectas los 12V. Caída baja (~0.2–0.3V a esta corriente).
- **TVS 5.6V (SMAJ6.0A)** a masa: recorta **sobretensiones/picos** (opcional pero recomendable).
- **Condensador 10µF** a masa: estabiliza la entrada.

Caída total: 5V − polyfuse(~0.1) − Schottky(~0.25) ≈ **4.6V** en VIN → el AMS1117 da 3.3V de sobra
(la lógica consume <100 mA). Mantén el cable corto para no perder más tensión.

### Alternativa "todo en uno"
Un **módulo de protección USB** (sobretensión + sobrecorriente, los venden baratos) intercalado entre
el USB y el VIN del AMS1117 hace lo mismo sin montar componentes sueltos.

## Cableado completo del USB independiente (datos + alimentación)

Un solo conector USB hacia la Pi → alimenta la lógica **y** lleva Klipper por USB:

| Hilo USB | Va a | Notas |
|---|---|---|
| **5V+ (rojo)** | AMS1117 **VIN** (con la protección de arriba) | alimenta la lógica 3.3V |
| **D+ (verde)** | MCU **PA12** + **pull-up 1.5kΩ a 3.3V** | datos USB Klipper |
| **D- (blanco)** | MCU **PA11** | datos USB Klipper |
| **GND (negro)** | masa de la placa | común |

> PA11/PA12 están **contiguos a SWDIO (PA13)**, que el reversing identificó. Ver
> [diagrams/k10-soldadura-usb.md](../diagrams/k10-soldadura-usb.md) para localizarlos y la pull-up.
> Guía visual de puntos: [reference/images/k10-usb-solder-guide.jpg](images/k10-usb-solder-guide.jpg).

## Seguridad importante
- Esto alimenta **solo la lógica**. El **calefactor NO** debe activarse sin termistor validado y sin
  los 12V; Klipper lo protege, pero no fuerces calentamiento con USB.
- No intentes mover motores ni calentar desde los 5V del USB (no hay corriente para eso).
- GND **común** entre USB/Pi y placa. Señales a 3.3V hacia el MCU (D+/D-).

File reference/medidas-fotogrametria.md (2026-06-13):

# Medidas de la placa K10 por fotogrametría

Como no hay cotas publicadas del PCB de la K10, se estimaron a partir de las fotos cenitales del
reversing usando un **componente de tamaño estándar como regla**. Método reproducible con
`reference/images/` + OpenCV (scripts ad-hoc).

## Método

1. **Referencia de escala = encapsulado del MCU.** El chip se lee como **GD32F303 (GigaDevice, ARM)**.
   Se contaron los pines por lado mediante perfil de intensidad: **~12 pines/lado → LQFP48**
   (no LQFP64). El LQFP48 tiene **cuerpo de 7.0 mm** (lead-span 9.0 mm).
2. Medido el cuerpo del MCU en la foto frontal: **≈167 px** → escala **0.0419 mm/px**
   (cross-check con lead-span 9 mm ≈ 220 px → 0.0409 mm/px; coinciden en ~0.041).
3. Contorno del PCB por perfiles de brillo (placa oscura sobre fondo claro), en ambas caras.

## Resultados

| Magnitud | Valor | Confianza | Notas |
|---|---|---|---|
| **Contorno PCB** | **79 × 53 mm** | Alta (±2 mm) | Aspecto 1.50 coincide por las dos caras |
| Grosor PCB | 1.6 mm | Asumido | estándar de industria |
| Patrón de agujeros (4 esquinas) | ~72 × 44 mm centro-a-centro | Media (±2-3 mm) | esquinas inferiores ruidosas (QR/botón) |
| Inset de agujeros desde borde | ~3.5 × 4.5 mm | Media | derivado del patrón |
| **Altura de componentes** | **NO medible** | — | las fotos cenitales no dan altura; usar calibre |

## Escala — verificación cruzada

- Frontal: 1881 × 1258 px × 0.0419 = **78.8 × 52.7 mm** (aspecto 1.495).
- Trasera: 1882 × 1191 px (aspecto 1.580; ligero escorzo vertical o sobresale el botón redondo).
- Ambas dan ~79 mm de ancho → el contorno es robusto.

## Implicación de diseño

- El **contorno (79×53)** es fiable → la caja se dimensiona con seguridad.
- El **patrón de agujeros** NO es lo bastante preciso para alinear standoffs a ciegas.
  → La caja debe **retener el PCB por su contorno** (repisa perimetral + presión de la tapa),
  usando los standoffs solo como apoyo aproximado. Verificar los 4 agujeros con calibre antes de
  fijar tornillos de PCB.
- **COMP_H (altura)**: medir con calibre el componente más alto (condensadores/conectores). Solo
  afecta al alto de la caja, que lleva margen; valor provisional 17 mm.

## Layout de puertos por borde (verificado en fotos)

- Borde con 4 conectores de motor (X/Y/Z/E) | jack DC 12V + USB-C | mazo del cabezal (HE+TH+FAN) |
  ranura microSD | botones del reverso (S3 Retract, S4 Feed, S5 ▲ Print, S6-S9 niveles).

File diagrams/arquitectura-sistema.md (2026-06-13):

# Diagrama — Arquitectura del sistema

## Vista lógica (multi-MCU Klipper)

```mermaid
graph TD
    subgraph PI["Raspberry Pi (host)"]
        K["Klipper host<br/>(cinemática, look-ahead,<br/>input shaping, PID)"]
        M["Moonraker (API)"]
        W["Mainsail / Fluidd (web)"]
        W --> M --> K
    end

    K -- "USB serie<br/>/dev/serial/by-id" --> CNC
    K -- "USB serie<br/>(adaptador USB-TTL)" --> K10

    subgraph CNC["MCU 'cnc' — Arduino Uno (ATmega328P) + CNC Shield V3"]
        X["Stepper X + endstop"]
        Y["Stepper Y + endstop"]
        Z["Stepper Z + endstop"]
        P["Sonda Z (opcional)"]
    end

    subgraph K10["MCU 'k10' — placa GD32F303 (cabezal)"]
        E["Extrusor (stepper)"]
        H["Calefactor (MOSFET HY1403)"]
        T["Termistor (ADC)"]
        F["Fan"]
    end

    CNC --> MEC["Mecánica Epson reciclada<br/>NEMA17 · ~280x280x70 mm"]
    K10 --> HEAD["Cabezal K10<br/>hotend + extrusor"]
```

## Vista física (alimentación y masas)

```
   Fuente potencia (12-24V) ──► CNC Shield ──► motores NEMA17 (XYZ)
   Fuente K10 (~12V)        ──► placa K10  ──► calefactor + extrusor
   Fuente 5V/3A             ──► Raspberry Pi
                                  │
                                  ├─USB─► Arduino Uno (lógica + CNC Shield)
                                  └─USB─► adaptador USB-TTL ─UART(3.3V)─► GD32 K10

   ⚠️ TODAS las masas (GND) unidas. Señales al GD32 a 3.3V. Ver docs/06.
```

> Opción B/C: el bloque "MCU k10" se sustituye por un board de impresora con pinout conocido
> (sin reversing ni soldadura SMD). La topología lógica es idéntica.

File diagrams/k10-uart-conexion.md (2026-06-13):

# Diagrama — Comunicación de la K10 con el host (3 vías)

La K10 **no tiene USB de datos de fábrica** (su USB-C es solo alimentación, USB-PD). Hay **tres**
formas de darle a Klipper un enlace con la K10. Todas trabajan a **3.3 V** (nivel del GD32).

- **A. USB nativo del GD32** (recomendada) — PA11/PA12 + pull-up 1.5 kΩ → cable USB. Aparece como
  dispositivo Klipper por USB. **Esquema de soldadura completo:** [k10-soldadura-usb.md](k10-soldadura-usb.md).
- **B. UART por GPIO de la Raspberry Pi** — sin comprar nada, 3 cables a la cabecera de la Pi.
- **C. UART + adaptador USB-TTL** — si prefieres por USB y ya tienes un adaptador 3.3 V.

> No necesitas comprar adaptador: con la **A** (cable USB) o la **B** (GPIO de la Pi) te apañas con lo
> que ya tienes. Detalle y seguridad en [docs/04](../docs/04-soldadura-uart-k10.md).

---

## Fotos reales de la placa (K10 V2.1)

Placa K10 V2.1 - cara de componentes (MCU GD32 en el centro)

`1-4` = drivers **HR4988** (X/Y/Z/E) · MCU **GD32F303RCT6** (centro) · MOSFET calefactor **HY1403** ·
regulador **AMS1117** · controlador **PW6606** (USB-PD).

Cableado de la K10 en su carcasa

---

## A. USB nativo del GD32 (recomendada — la opción que propusiste)

PA12 = USB D+, PA11 = USB D−. Necesita **1.5 kΩ de D+ a 3.3 V**. Ver el esquema eléctrico de soldadura
completo en **[k10-soldadura-usb.md](k10-soldadura-usb.md)**. Esquema lógico:

```text
     PLACA K10 (GD32F303)         RASPBERRY PI
    +----------------+        +------------------+
    |                |        |                  |
    | PA12 D+  o     |--------| o  D+   (USB)    |
    | PA11 D-  o     |--------| o  D-   (USB)    |
    | GND      o     |--------| o  GND           |
    |                |        |                  |
    +----------------+        +------------------+
     (+ pull-up 1.5 kΩ de PA12/D+ a 3.3 V — OBLIGATORIA)
     VBUS +5V del USB: NO conectar al MCU.  D+/D- cortos y trenzados.
```

Klipper: interfaz de comunicación **USB (PA11/PA12)**. Resultado: `/dev/serial/by-id/usb-Klipper_stm32f103xe_...`.

---

## B. UART por GPIO de la Raspberry Pi (sin comprar nada)

```text
    PLACA K10 (GD32F303, 3.3 V)            RASPBERRY PI  (cabecera GPIO, 3.3 V)
    +------------------------+            +------------------------------------+
    |                        |   cable A  |                                    |
    |   USART1 TX = PA9   o--|----------->|--o RXD = GPIO15   (pin fisico 10)  |
    |                        |   cable B  |                                    |
    |   USART1 RX = PA10  o--|<-----------|--o TXD = GPIO14   (pin fisico 8)   |
    |                        |   cable C  |                                    |
    |   GND               o--|------------|--o GND            (pin fisico 6)   |
    |                        |            |                                    |
    +------------------------+            +------------------------------------+

    Regla: TX de un lado --> RX del otro (cruzado). Si no conecta, intercambia A y B.
```

En la Pi: `sudo raspi-config` → Serial → consola por serie **NO**, hardware serial **SÍ**.
Klipper: comunicación **Serial (USART1, PA9/PA10)**. En `[mcu k10]`: `serial: /dev/ttyAMA0`.

---

## C. UART + adaptador USB-TTL (3.3 V)

```text
     PLACA K10 (3.3 V)         ADAPTADOR USB-TTL (3.3 V)
    +----------------+        +----------------------+
    |                |        |                      |
    | TX = PA9   o   |------->| o  RX                |
    | RX = PA10  o   |<-------| o  TX                |
    | GND        o   |--------| o  GND               |
    |                |        | VCC 3.3 V (NO usar)  |
    |                |        |                      |
    +----------------+        +----------------------+
              (el adaptador va por USB a la Pi)
```

Mismo cruce TX↔RX, GND común, VCC del adaptador sin conectar. Adaptador **en 3.3 V** (5 V daña el GD32).

---

## SWD — para flashear / volcar firmware (no es la comunicación de Klipper)

```text
    GD32 K10:   SWDIO = PA13     SWCLK = PA14     NRST = PB4     (+ GND y 3.3 V)

    Programador:  ST-Link V2     o     Raspberry Pi Pico (Picoprobe) + OpenOCD
```

Pines SWD del GD32 en la K10

Montaje de depuración SWD sobre la K10

---

## Tabla resumen de cableado

| Señal | Pin K10 (GD32) | Opción A — USB nativo | Opción B — Pi GPIO | Opción C — USB-TTL  |
|---|---|---|---|---|
| D+ / TX | PA12 (D+) / PA9 (TX)  | PA12 → D+ del cable USB | — | — |
| D- / RX | PA11 (D-) / PA10 (RX) | PA11 → D- del cable USB | — | — |
| Pull-up | — | 1.5 kΩ de PA12 a 3.3 V  | no aplica | no aplica |
| TX (UART) | PA9 | — | → RXD GPIO15 (pin 10) | → RX del adaptador  |
| RX (UART) | PA10 | — | → TXD GPIO14 (pin 8)  | → TX del adaptador  |
| GND | GND | → GND del USB | → GND (pin 6) | → GND del adaptador |

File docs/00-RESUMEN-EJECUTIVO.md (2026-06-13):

# 00 — Resumen ejecutivo y matriz de decisión

Lee esto antes de comprar o soldar nada. Resume los hallazgos de la investigación técnica y
te plantea la decisión de arquitectura que condiciona todo lo demás.

---

## Hallazgos críticos (verificados)

### 1. La K10 es el chip correcto para Klipper, la K9 no
| Impresora | MCU | ¿Klipper? |
|---|-----|---|
| **K10** | **GigaDevice GD32F303RCT6** (Cortex-M4) | ✅ **Sí** — se compila como STM32F103 + bootloader 28 KiB |
| K9 | ARERY **AT32F403ARCT7** (clon STM32F1, Artery) | ❌ No soportado por Klipper |

Sacrificar la K10 y conservar la K9 (que dominas) es, por casualidad, la decisión correcta:
el GD32 de la K10 **sí** corre Klipper; el Artery de la K9 **no**.
Fuente: [reversing K10](https://palmarci.me/blog/2025-05-02-easythreed-k10-3d-printer-main-board-reversing/index.html),
[Hackaday K9](https://hackaday.com/2024/02/12/easythreed-k9-the-value-in-a-e72-aliexpress-fdm-3d-printer/),
[Klipper en GD32F303](https://klipper.discourse.group/t/installing-klipper-on-ender-3-4-2-2-board-and-gd32f303-chip/8165).

### 2. "Soldar el USB de la K10" NO funciona como esperas
- El **USB-C de la K10 es solo alimentación (USB-PD)**: va a un controlador PD (PW6606), **no al MCU**.
- **No hay chip USB-serie** (CH340/CP2102). De fábrica se opera **solo por microSD**.
- Klipper necesita un enlace serie/USB permanente con el host. Para tenerlo en la K10 hay que
  **soldar 3 cables (TX, RX, GND) directamente a pines USART del GD32** (paso 0.5 mm) y conectar
  un **adaptador USB-TTL** (FTDI/CP2102/CH340) hacia la Pi. Ver [04](04-soldadura-uart-k10.md).

### 3. El verdadero coste de la K10 es reversear el pinout
- **Nadie ha publicado** el pinout completo de la K10 ni un `printer.cfg`.
- Tendrás que mapear qué pin del GD32 va a: cada driver HR4988 (step/dir/enable), el MOSFET del
  calefactor, el ADC del termistor, el fan y los endstops. Metodología en [10](10-reversing-pinout-k10.md).
- Tienes a favor: **SWD accesible** (PA13/PA14/NRST), RDP desactivado en la unidad analizada, y un
  **volcado de firmware** público del que extraer pistas.

### 4. El Arduino Uno como MCU de Klipper: viable pero justo
- ATmega328P **sí** está soportado (16 MHz). Referencia directa: [klipper-drawbot](https://github.com/gwisp2/klipper-drawbot) (Uno + CNC Shield V3).
- Límites reales: **flash 32 KB** (hay que desactivar features en menuconfig), **~99k pasos/s con 3 ejes
  simultáneos**, riesgo de `Timer too close` si abusas de microstepping. Quédate en **1/16**.

### 5. Volumen real de la K10
La cama original de la K10 es **100×100×100 mm**. La ganancia de tu CNC (~280×280×70 mm en XY,
menos en Z) es enorme para X/Y, pero **el Z de ~70 mm es bajo** para una impresora — tenlo en cuenta
al diseñar la bancada/portaboquilla. Ver [03](03-hardware-cnc.md).

---

## Matriz de decisión de arquitectura

Tres caminos para gobernar el **cabezal** (hotend + extrusor + termistor + fan). El CNC siempre
hace X/Y/Z con el Arduino+Klipper; lo que cambia es **quién controla el cabezal**.

| | **A — Klipper en la K10** (fiel a tu idea) | **B — Placa dedicada** (pragmático) | **C — Todo en una placa** (máxima simplicidad) |
|---|---|---|---|
| Cabezal lo controla | Placa K10 con Klipper (toolhead MCU) | Una placa barata Klipper-friendly (SKR Mini / MKS / Ender 4.2.2 GD32) | Esa misma placa controla **también** X/Y/Z |
| Arduino+CNC Shield | XYZ | XYZ | Se jubila (o queda de repuesto) |
| Reutiliza la K10 | ✅ Sí (su gracia) | ❌ Solo el hotend/motor como piezas sueltas | ❌ |
| Soldadura SMD en MCU | ✅ Necesaria (UART al GD32) | ❌ No | ❌ No |
| Reversing de pinout | ✅ Necesario (lo más duro) | ❌ No | ❌ No |
| Multi-MCU | Sí (2 MCU) | Sí (2 MCU) | No (1 MCU) |
| Coste € | ~0 (reusas) + adaptador USB-TTL (~3€) | +15–25€ (placa) | +25–40€ (placa con drivers para 4–5 motores) |
| Dificultad | Alta (reversing + microsoldadura) | Media | Baja |
| Riesgo de bloqueo | Alto (pinout desconocido) | Bajo | Muy bajo |
| Valor "maker"/aprendizaje | Máximo | Medio | Bajo |

### Recomendación honesta
- Si esto es un **reto de ingeniería** y disfrutas reverseando: **Opción A**. Toda la documentación
  está preparada para ella (es el "camino principal" del repo). Empieza por validar comms y pinout
  ([10](10-reversing-pinout-k10.md)) **antes** de tocar mecánica.
- Si quieres **una impresora mejor funcionando pronto** con bajo riesgo: **Opción B**. Reutilizas el
  hotend y el motor de la K10 como piezas, y un board barato te da heater+termistor+extrusor sin reversing.
- **Opción C** solo si te cansas del Arduino: un único board decente (p.ej. SKR Mini E3) mueve 4–5
  steppers + hotend + cama y simplifica todo, a costa de no usar ni Arduino ni placa K10.

> Sugerencia de ruta: monta y **valida primero el CNC con Klipper (Opción B-mínima: solo XYZ moviéndose)**.
> Es la parte documentada y de bajo riesgo. Con el CNC ya homing y moviéndose, decides si atacas el
> reversing de la K10 (A) o enchufas un board (B/C) para el cabezal. Así nunca te quedas bloqueado.

---

## Orden de trabajo sugerido

1. **Host listo** → Raspberry Pi con KIAUH + Klipper + Moonraker + Mainsail ([07](07-instalacion-host-pi.md)).
2. **CNC con Klipper** → flashear ATmega328P, mapear CNC Shield, homing y movimiento XYZ ([03](03-hardware-cnc.md), [05](05-flasheo-klipper.md), [06](06-cableado-pines.md)).
3. **Calibrar XYZ** → `rotation_distance` por medición, sentido de giro, endstops ([08](08-calibracion.md)).
4. **Decidir cabezal** → Opción A (reversing K10, [10](10-reversing-pinout-k10.md) + [04](04-soldadura-uart-k10.md)) o B/C (board dedicado).
5. **Multi-MCU** → unir cabezal + XYZ en un `printer.cfg` con prefijos de pin ([01](01-arquitectura.md)).
6. **Sonda Z + bed mesh** → nivelado automático ([09](09-sensores-zprobe.md)).
7. **Afinado** → PID, extrusor, input shaping ([08](08-calibracion.md)).

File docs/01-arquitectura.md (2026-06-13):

# 01 — Arquitectura del sistema (multi-MCU Klipper)

## Concepto

Klipper separa el "pensar" del "ejecutar":

- El **host** (Raspberry Pi) hace **toda** la planificación: cinemática, look-ahead,
  aceleración, input shaping, pressure advance. Convierte el G-code en una lista temporizada
  de pasos.
- Cada **microcontrolador (MCU)** solo ejecuta los pasos que el host le manda, con timing
  preciso. Es "tonto" a propósito.

Esto permite **multi-MCU**: varios microcontroladores conectados a la misma Pi, cada uno
responsable de unos actuadores. El host sincroniza sus relojes automáticamente y reparte el
trabajo. Es exactamente el patrón "toolhead board" que usan impresoras comerciales modernas.

## Topología de esta frankenprinter (Opción A)

```
                       ┌─────────────────────────────┐
                       │      Raspberry Pi (host)     │
                       │  Klipper host + Moonraker +  │
                       │       Mainsail/Fluidd        │
                       └──────────────┬───────┬───────┘
                          USB serie   │       │  USB serie
                  (/dev/serial/by-id) │       │ (/dev/serial/by-id)
                       ┌──────────────┘       └──────────────┐
                       ▼                                      ▼
          ┌────────────────────────┐            ┌───────────────────────────┐
          │  MCU "cnc"             │            │  MCU "k10"                │
          │  Arduino Uno (328P)    │            │  Placa K10 (GD32F303)     │
          │  + CNC Shield V3       │            │  (UART soldado al MCU)    │
          ├────────────────────────┤            ├───────────────────────────┤
          │  X stepper + endstop   │            │  Extrusor (stepper)       │
          │  Y stepper + endstop   │            │  Calefactor hotend (MOSFET)│
          │  Z stepper + endstop   │            │  Termistor (ADC)          │
          │  Sonda Z (opcional)    │            │  Fan de capa / hotend     │
          └────────────────────────┘            └───────────────────────────┘
                  motores NEMA17                     cabezal de la K10
                  (mecánica Epson)
```

> En la **Opción B/C** el bloque "MCU k10" se sustituye por una placa de impresora barata
> (mismo rol de toolhead), o por una única placa que asume también X/Y/Z. La lógica de
> Klipper es idéntica; solo cambian los `serial:` y los nombres de pin.

## Cómo se declara en `printer.cfg`

Un MCU es el **principal** (`[mcu]`, sin nombre) y el resto **secundarios** (`[mcu nombre]`).
Cada pin de un MCU secundario se referencia con el **prefijo** `nombre:`.

```ini
# --- MCU principal: el CNC (ejes) ---
[mcu]
serial: /dev/serial/by-id/usb-1a86_USB_Serial-if00-port0   # tu Arduino (ver ls by-id)

# --- MCU secundario: el cabezal K10 ---
[mcu k10]
serial: /dev/serial/by-id/usb-Klipper_stm32f103xe_XXXX-if00

[stepper_x]
step_pin: PD2            # sin prefijo -> MCU principal (Arduino)
dir_pin: PD5
enable_pin: !PB0
...

[extruder]
step_pin: k10:PB?        # con prefijo -> MCU k10 (pin a determinar por reversing)
heater_pin: k10:PA?
sensor_pin: k10:PA?
...
```

Reglas:
- Los **modificadores de pin** van antes del prefijo: `^k10:PA1` (pull-up), `!k10:PB0` (invertir),
  `^!cnc:PB4` (ambos).
- Un eje movido por **varios** steppers (p.ej. doble Z) debe tener **todos** sus steppers en el
  **mismo** MCU.

## Sincronización de relojes y homing multi-MCU

- Klipper **sincroniza los relojes** de todos los MCU con el host de forma continua y automática.
  No hay que configurar nada.
- Cuidado con el **homing/probing cuando el endstop está en un MCU distinto** al de los steppers
  de ese eje. Hay latencia de red; puede haber sobrepaso de hasta ~0.25 mm a 10 mm/s. Por eso en
  esta arquitectura conviene que **los endstops y la sonda Z estén en el MISMO MCU que los ejes
  X/Y/Z** (el del CNC). El cabezal (K10) no lleva endstops, solo extrusor + térmica.
- Documentación oficial: <https://www.klipper3d.org/Multi_MCU_Homing.html>

## Identificación estable de puertos serie

Nunca uses `/dev/ttyUSB0` / `/dev/ttyACM0` en la config: cambian al reiniciar o según el orden de
enchufe. Usa el ID persistente:

```bash
ls /dev/serial/by-id/*
```

Si una placa usa un **CH340** clónico (sin número de serie único), `by-id` puede no distinguir dos
placas iguales. En ese caso identifica por **puerto físico**:

```bash
ls /dev/serial/by-path/*
```

y mantén siempre cada MCU enchufado en el **mismo puerto USB** de la Pi (o usa un hub con posiciones fijas).

## Flujo de una impresión

1. Subes el G-code a Mainsail (servido por Moonraker).
2. El host Klipper lee el G-code, aplica cinemática cartesiana + aceleración + input shaping +
   pressure advance, y genera comandos temporizados.
3. Reparte: pasos de X/Y/Z → MCU `cnc`; pasos de extrusor + PWM de calefactor/fan → MCU `k10`.
4. Cada MCU ejecuta en su reloj; el host mantiene todo sincronizado.
5. La térmica (termistor) la lee el MCU `k10` y reporta al host, que cierra el lazo PID.

## Referencias
- Config multi-MCU: <https://www.klipper3d.org/Config_Reference.html> (secciones `[mcu]` / `[mcu nombre]`)
- Multi-MCU homing: <https://www.klipper3d.org/Multi_MCU_Homing.html>
- Overview Klipper: <https://www.klipper3d.org/Overview.html>

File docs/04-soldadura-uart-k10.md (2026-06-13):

# 04 — Comunicar la K10 con el host (USB nativo / UART)

> El USB-C de la K10 **no lleva datos al MCU** (es solo USB-PD de alimentación). Hay tres formas de
> darle a Klipper un enlace con la K10. Todas a **3.3 V** (nivel del GD32). Diagramas y esquema de
> soldadura: [diagrams/k10-uart-conexion.md](../diagrams/k10-uart-conexion.md) y
> [diagrams/k10-soldadura-usb.md](../diagrams/k10-soldadura-usb.md).

## Resumen de las tres vías

| Vía | Qué soldar | Compras | Resultado en la Pi |
|---|---|---|---|
| **A. USB nativo** (recomendada) | PA12(D+), PA11(D−), GND + **R 1.5 kΩ** de D+ a 3.3 V, a un cable USB | nada (un cable USB) | `/dev/serial/by-id/usb-Klipper_...` |
| **B. UART por GPIO de la Pi** | PA9(TX), PA10(RX), GND a la cabecera GPIO de la Pi | nada | `/dev/ttyAMA0` |
| **C. UART + adaptador USB-TTL** | PA9, PA10, GND al adaptador (3.3 V) | adaptador (~3–6 €)  | `/dev/serial/by-id/...` |

---

## A. USB nativo del GD32 (recomendada)

El GD32F303 tiene **USB nativo**: **PA12 = D+**, **PA11 = D−** (igual que STM32F103). El reversing
confirmó que esa función está presente pero sin usar. Llevándola a un cable USB obtienes un dispositivo
Klipper USB de verdad, sin adaptador.

- **Imprescindible**: resistencia de **1.5 kΩ de PA12 (D+) a 3.3 V**. El GD32/STM32F103 **no** tiene
  pull-up interna; sin ella el USB **no enumera**.
- **VBUS (+5V, hilo rojo del USB): NO conectar** al MCU (la K10 se alimenta por su DC).
- **GND común**: el hilo negro del USB une masas. **D+/D− cortos y trenzados.**
- Klipper: interfaz de comunicación **USB (PA11/PA12)**.

👉 **Esquema eléctrico de soldadura completo, colores de cable y cómo localizar PA11/PA12 en el chip:
[diagrams/k10-soldadura-usb.md](../diagrams/k10-soldadura-usb.md).**

Fuentes: <https://klipper.discourse.group/t/klipper-support-on-stm32f103-over-usb/25074> ·
<https://klipper.discourse.group/t/support-for-new-creality-boards-4-2-2-with-gd32f303/3016>

---

## B. UART por GPIO de la Raspberry Pi (sin comprar nada)

Usa una USART del GD32 (USART1: **PA9 = TX**, **PA10 = RX**) contra el UART hardware de la Pi.

```text
   K10 (GD32, 3.3 V)            Raspberry Pi (cabecera GPIO, 3.3 V)
   PA9  (TX)  ----------------> GPIO15 / RXD   (pin físico 10)
   PA10 (RX)  <---------------- GPIO14 / TXD   (pin físico 8)
   GND        -----------------  GND           (pin físico 6)
```

- Regla: **TX de un lado → RX del otro** (cruzado). Si no conecta, intercambia los dos cables de datos.
- En la Pi: `sudo raspi-config` → Interface → Serial → consola por serie **NO**, hardware serial **SÍ**. Reinicia.
- Klipper: comunicación **Serial (USART1, PA9/PA10)**. En `[mcu k10]`: `serial: /dev/ttyAMA0` (o `/dev/serial0`).
- 3.3 V nativo en ambos lados; **no** uses los pines de 5 V de la Pi para señal.

---

## C. UART + adaptador USB-TTL (si prefieres por USB y ya tienes adaptador)

Igual que B pero a un adaptador FTDI/CP2102/CH340 **en modo 3.3 V**, que va por USB a la Pi.
Mismo cruce TX↔RX, GND común, **VCC del adaptador sin conectar**. Aparece como `/dev/serial/by-id/...`.

> Un adaptador en 5 V puede dañar el GD32. Si no tienes adaptador y el host es una Pi, usa la **A** o la **B**.

---

## ¿Cuál elegir?

- **A (USB nativo)** es la más limpia (USB real) y solo añade una resistencia de 1.5 kΩ. Es la opción
  recomendada.
- **B (UART por GPIO)** es el plan B sin comprar ni soldar D+/D−: 3 cables a la Pi.
- **C** solo si ya tienes un adaptador USB-TTL 3.3 V o el host no es una Pi.

En las tres: localiza los pines con multímetro + [docs/10](10-reversing-pinout-k10.md), usa AWG30, fija con
kapton (alivio de tensión), y **masa común** siempre.

---

## Seguridad (común a todas)

- **3.3 V** en todas las señales hacia el GD32. Nada de 5 V en D+/D−/UART/ADC.
- **GND común** entre K10, Pi y/o adaptador.
- Alimentaciones de potencia (motores, calefactor) **separadas** de la lógica.
- Antes de soldar, placa **sin alimentar**, verifica cada pad con continuidad.

---

## Checklist de validación de comms

- [ ] Klipper flasheado en la K10 (ver [05](05-flasheo-klipper.md)) con la interfaz correcta (USB o Serial).
- [ ] (A) pull-up 1.5 kΩ en D+ puesta · (B) `raspi-config` con hardware serial activado.
- [ ] `ls /dev/serial/by-id/*` (A/C) o `/dev/ttyAMA0` (B) presente.
- [ ] `serial:` de `[mcu k10]` apunta a la ruta correcta.
- [ ] `FIRMWARE_RESTART` sin "mcu 'k10': Unable to connect".
- [ ] Si falla UART: intercambia TX/RX; confirma baud; 3.3 V; GND común.
- [ ] Si falla USB: revisa la pull-up de 1.5 kΩ y que D+/D− no estén cambiados.

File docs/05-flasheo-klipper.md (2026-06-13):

# 05 — Flasheo de Klipper en los dos MCU

Cada MCU necesita el firmware de Klipper compilado **para su chip**. Se compila en la Pi
(`~/klipper`) con `make menuconfig` + `make`, y se flashea por su vía. El proceso host (que hace la
cinemática) es común; lo que cambia es el binario de cada MCU.

---

## A. Arduino Uno (ATmega328P) — el CNC

### menuconfig
```bash
cd ~/klipper
make clean
make menuconfig
```
Opciones:
```
[*] Enable extra low-level configuration options
    Micro-controller Architecture: Atmega AVR
    Processor model: atmega328p
    Processor speed: 16 MHz
    Communication interface: Serial (UART)
    Baud rate for serial port: 250000
```
> Flash de 32 KB justa: **desactiva** lo que no uses para que el binario quepa. Si `make` se queja de
> tamaño, quita features opcionales.

### Compilar y flashear
```bash
make
# El Uno ya trae bootloader Arduino/Optiboot -> NO necesitas ISP externo:
avrdude -c arduino -p atmega328p -P /dev/ttyACM0 -b 115200 -D \
        -U flash:w:out/klipper.elf.hex:i
```
- Puerto: `/dev/ttyACM0` (Uno genuino) o `/dev/ttyUSB0` (clon CH340). Mejor usa el `by-id`.
- Baud bootloader: **115200** (Optiboot moderno). Clones viejos: prueba **57600** si da "out of sync".
- `-D` = no borrar todo (necesario con bootloader).
- Alternativa: `make flash FLASH_DEVICE=/dev/serial/by-id/usb-...`.
- Vía KIAUH: `[Advanced] → [Build + Flash]`.

> Solo necesitas un ISP externo si quisieras **regrabar el bootloader**, no para Klipper.

---

## B. Placa K10 (GD32F303 ≈ STM32F103) — el cabezal (Opción A)

El GD32F303 se trata como **STM32F103**. Hay **dos** vías de flasheo:

### B.1 — Vía SWD (recomendada para el primer flasheo): ST-Link / Picoprobe + OpenOCD
La K10 expone SWD: **SWDIO=PA13, SWCLK=PA14, NRST=PB4** (ver [02](02-hardware-k10.md)).

menuconfig:
```bash
cd ~/klipper && make menuconfig
```
```
Micro-controller Architecture: STMicroelectronics STM32
Processor model: STM32F103
Bootloader offset: No bootloader        <-- al flashear por SWD vas a 0x08000000
Clock Reference: 8 MHz crystal          <-- verifica el cristal de la placa (8 MHz típico)
Communication interface: <segun la via que elijas, ver docs/04>
   - Opción A (USB nativo, recomendada): USB (on PA11/PA12)   <-- requiere R 1.5kΩ en D+
   - Opción B/C (UART):                  Serial (on USART1 PA9/PA10)
[*] Disable SWD at startup (GD32)        <-- IMPORTANTE para GD32F303
Baud rate: 250000                        <-- solo aplica a Serial (no a USB)
```
Compilar y flashear con OpenOCD/ST-Link:
```bash
make
# Con ST-Link V2:
openocd -f interface/stlink.cfg -f target/stm32f1x.cfg \
        -c "program out/klipper.bin verify reset exit 0x08000000"
```
> El "Disable SWD at startup" libera PA13/PA14 (que en GD32 a veces dan problemas) y es lo que hace que
> el GD32F303 arranque Klipper de forma fiable.

### B.2 — Vía bootloader SD (sin tocar SWD)
La K10 trae el bootloader MKS que carga un `.bin` desde microSD a flash en **offset 0x4000** (= 16 KiB).
En ese caso:
```
Bootloader offset: 16KiB bootloader
```
Genera `out/klipper.bin`, renómbralo a algo único acabado en `.bin` (que **no** sea igual al último
flasheado), cópialo a la microSD, insértala y enciende. El bootloader lo graba.
> Ojo: el offset del bootloader (16KiB vs 28KiB) depende del bootloader real de la placa. El de Creality
> 4.2.2 GD32 usa **28KiB**; el MKS Lite de EasyThreed apunta a **0x4000 = 16KiB**. **Prueba 16KiB primero**
> (es lo que indica el reversing de la K10); si no arranca, prueba 28KiB. Conserva siempre un **volcado del
> firmware original** por SWD antes de sobreescribir (ver abajo).

### B.3 — Salvaguarda: vuelca el firmware original primero
Antes de sobreescribir nada en la K10, con SWD:
```bash
openocd -f interface/stlink.cfg -f target/stm32f1x.cfg \
        -c "init; reset halt; dump_image k10_original.bin 0x08000000 0x40000; exit"
```
Guarda `k10_original.bin` en `reference/`. Si algo sale mal, puedes restaurar Marlin.

---

## Verificación tras flashear

```bash
ls /dev/serial/by-id/*          # cada MCU debe aparecer
```
En `printer.cfg` pon esos `by-id` en `[mcu]` (CNC) y `[mcu k10]`. Luego en Mainsail: `FIRMWARE_RESTART`.
Si conecta, en la consola verás la versión de Klipper de cada MCU. Comprueba que **las versiones host y
MCU coinciden** (si no, recompila/reflashea).

---

## Errores típicos
| Síntoma | Causa probable | Solución |
|---|---|---|
| `avrdude: stk500_recv(): programmer is not responding` | baud bootloader o puerto | prueba 57600; revisa /dev correcto; sin el monitor serie abierto |
| `Unable to connect` (k10) | TX/RX cruzados, baud, 3.3V | intercambia TX/RX; mismo baud host/MCU; GND común |
| GD32 no arranca tras SWD | falta "Disable SWD at startup" u offset | activa esa opción; revisa offset/cristal |
| Versiones host/MCU distintas | recompilaste host pero no MCU (o al revés) | reflashea con el mismo commit |

Fuentes: <https://www.klipper3d.org/Installation.html> · <https://www.klipper3d.org/Bootloaders.html> ·
GD32F303: <https://klipper.discourse.group/t/installing-klipper-on-ender-3-4-2-2-board-and-gd32f303-chip/8165>

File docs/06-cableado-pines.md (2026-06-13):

# 06 — Cableado y pinout (referencia rápida)

Tabla maestra de conexiones. Los pines de la K10 marcados con `??` se rellenan tras el
[reversing](10-reversing-pinout-k10.md).

---

## MCU "cnc" — Arduino Uno + CNC Shield V3

| Señal | Pin Klipper | Conector físico shield |
|---|---|---|
| X step / dir | PD2 / PD5 | slot driver X |
| Y step / dir | PD3 / PD6 | slot driver Y |
| Z step / dir | PD4 / PD7 | slot driver Z |
| Enable (común) | !PB0 | EN (los 4 drivers) |
| X endstop | ^PB1 | header X+/X− (D9) |
| Y endstop | ^PB2 | header Y+/Y− (D10) |
| Z endstop | ^PB4 | header Z+/Z− (D12) |
| Sonda Z (si va aquí) | ^PB3 o un endstop libre | ver [09](09-sensores-zprobe.md) |

Motores NEMA17 a los slots X/Y/Z. **Bobinas**: si un motor va al revés o "vibra sin girar", el orden de
los 4 cables del conector está mal; reordena los pares de bobina (típico: A1,A2,B1,B2). Mejor que invertir
en software es cablear bien; el sentido se ajusta con `!` en `dir_pin`.

### Alimentación CNC Shield
- La shield se alimenta por su borna (típico 12–36 V según drivers/motores). **No** la alimentes solo por
  el USB del Arduino: el USB da lógica, los motores necesitan la borna de potencia.
- GND de la fuente de motores común con el Arduino (la shield ya une masas).

---

## MCU "k10" — placa GD32F303 (Opción A)

| Señal | Pin Klipper | Origen |
|---|---|---|
| Extrusor step / dir / enable | k10:P?? / k10:P?? / !k10:P?? | driver HR4988 del extrusor (reversing) |
| Calefactor hotend | k10:P?? | gate del MOSFET HY1403 (reversing) |
| Termistor (ADC) | k10:P?? | divisor del termistor (reversing) |
| Fan de capa | k10:P?? | salida fan (reversing) |
| UART al host | — | PA9(TX)/PA10(RX)/GND → adaptador USB-TTL (ver [04](04-soldadura-uart-k10.md)) |

Cabezal de la K10 = hotend + cartucho calefactor + termistor + motor extrusor + fan. Se quedan **en su
placa**; solo añades el UART y, si hace falta, recableas el fan a un pin controlable.

---

## Masas y alimentación (visión global)

```
   Fuente CNC (12-36V) ──► CNC Shield (motores XYZ) ──┐
                                                       ├── GND COMÚN ──┐
   Fuente K10 (≈12V)  ──► Placa K10 (hotend/extrusor) ┘               │
                                                                       │
   Raspberry Pi (5V propia) ──USB──► Arduino (lógica) ────────────────┤
                            └─USB──► adaptador USB-TTL ── K10 UART ────┘
```
- **Todas las masas (GND) deben estar unidas** entre sí (Pi, Arduino, adaptador, K10, fuentes). Sin masa
  común, la comunicación serie falla y los ADC dan lecturas erráticas.
- **Alimentaciones de potencia separadas** de la lógica (la Pi por su fuente de 5 V/3 A; los motores y el
  calefactor por sus fuentes).
- No mezcles 5 V y 3.3 V en líneas de señal hacia el GD32 (UART/ADC) — ver [04](04-soldadura-uart-k10.md).

---

## Endstops y sonda Z (dónde conectarlos)

- X/Y/Z endstops → en el **MCU cnc** (mismo MCU que los steppers de esos ejes → homing fiable).
- Sonda Z → preferiblemente también en el **MCU cnc**. Si necesitas un pin y no queda libre, considera
  usar `probe:z_virtual_endstop` con un sensor en un endstop de la shield. Detalle en [09](09-sensores-zprobe.md).

> Regla multi-MCU: el endstop de un eje debe estar en el **mismo MCU** que los steppers de ese eje para
> evitar sobrepaso por latencia. Por eso el cabezal (k10) **no** lleva endstops.

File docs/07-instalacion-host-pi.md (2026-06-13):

# 07 — Instalación del host (Raspberry Pi)

El host ejecuta el proceso Klipper (cinemática), Moonraker (API) y una interfaz web
(Mainsail o Fluidd). Lo más cómodo es instalar todo con **KIAUH**.

---

## Hardware del host

- **Raspberry Pi 3B/3B+/4/5** o **Zero 2 W** (suficiente para 2 MCU). Tarjeta microSD ≥ 16 GB clase 10.
- Fuente de **5 V / 3 A** propia y de calidad (no alimentes la Pi desde la electrónica de impresión).
- Conexión de red (Ethernet o Wi-Fi) para acceder a la web.

> Alternativa sin Pi: cualquier PC Linux (incluso un mini-PC x86) sirve de host. Klipper host corre en
> cualquier Linux; la Pi solo es lo habitual.

---

## 1. Sistema operativo

Graba **Raspberry Pi OS Lite (64-bit)** con Raspberry Pi Imager. En el imager, preconfigura:
hostname, usuario/clave, **SSH activado** y Wi-Fi. Arranca y entra por SSH:
```bash
ssh usuario@<hostname>.local
sudo apt update && sudo apt full-upgrade -y
sudo apt install -y git
```

---

## 2. KIAUH (instalador)

```bash
cd ~
git clone https://github.com/dw-0/kiauh.git
./kiauh/kiauh.sh
```
(Tienes una copia en `repos/kiauh/` para referencia.)

En el menú de KIAUH, **Install**, en este orden:
1. **Klipper** (elige Python 3; 1 instancia para empezar).
2. **Moonraker**.
3. **Mainsail** *(o Fluidd; elige una; puedes tener ambas pero comparten puerto)*.

KIAUH crea los servicios systemd (`klipper.service`, `moonraker.service`), el venv de Python, e instala
nginx para servir la web. Al terminar, abre `http://<ip-de-la-pi>/` en el navegador.

### Mainsail vs Fluidd
Ambas valen. **Mainsail** tiene UI muy pulida; **Fluidd** es algo más compacta. Para este proyecto da
igual; el repo asume Mainsail en los ejemplos. Repos: mainsail-crew/mainsail · fluidd-core/fluidd.

---

## 3. Estructura de archivos en la Pi

Tras instalar, lo relevante:
```
~/printer_data/config/printer.cfg     <-- tu config principal (edítala desde la web)
~/printer_data/config/moonraker.conf  <-- config de Moonraker
~/klipper/                            <-- código + 'make menuconfig' para firmware
~/moonraker/
```
Copia las configs de este repo (`klipper-config/`) a `~/printer_data/config/` adaptando los `serial:` y
los pines de la K10. Mantén los `include/` en una subcarpeta y referencia con `[include include/...]`.

---

## 4. Compilar y flashear firmware

Desde la Pi: `cd ~/klipper && make menuconfig && make` (ver [05 — Flasheo](05-flasheo-klipper.md) para las
opciones de cada MCU). KIAUH también ofrece `[Advanced] → [Build + Flash]`.

---

## 5. Identificar los MCU

```bash
ls /dev/serial/by-id/*
```
Apunta cada ruta y métela en `[mcu]` (CNC) y `[mcu k10]`. Reinicia Klipper: en Mainsail, botón
**FIRMWARE_RESTART**. Si conecta, ¡host listo!

---

## 6. Acelerómetro para input shaping (opcional, recomendado)

Si quieres input shaping medido (no a ojo), un **ADXL345** por SPI a la Pi:
- Habilita SPI en la Pi (`raspi-config` → Interface → SPI).
- Instala el "Linux MCU" de Klipper (proceso host como microcontrolador):
  KIAUH no lo hace solo; sigue <https://www.klipper3d.org/RPi_microcontroller.html> y
  <https://www.klipper3d.org/Measuring_Resonances.html>.
- Config y comandos en [08 — Calibración](08-calibracion.md).

---

## Servicios útiles
```bash
sudo systemctl status klipper moonraker
sudo systemctl restart klipper
journalctl -u klipper -f          # log en vivo (útil para depurar arranque)
```

Fuentes: <https://github.com/dw-0/kiauh> · <https://docs.mainsail.xyz/setup/kiauh/> ·
<https://www.klipper3d.org/Installation.html>

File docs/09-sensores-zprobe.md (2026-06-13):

# 09 — Sensores y sonda de eje Z

El nivelado automático (sonda Z + bed mesh) es de lo que más mejora una frankenprinter con cama no
perfectamente plana o no perpendicular a Z. Conecta la sonda preferiblemente en el **MCU del CNC**
(mismo MCU que los steppers XYZ → homing/probing fiable, sin latencia multi-MCU).

Concepto de pin en Klipper: `^` = pull-up, `!` = invertir (trigger en bajo). Si el endstop/sonda
aparece invertido (reporta "TRIGGERED" en reposo), añade/quita el `!`.

---

## Opciones de sonda

### A) BLTouch / CRTouch (servo, 5 hilos) — la más cómoda
```ini
[bltouch]
sensor_pin: ^PB3          # señal del probe (pin libre del CNC; ajusta)
control_pin: PB5          # PWM del servo (ajusta a un pin libre)
stow_on_each_sample: True
x_offset: -40.0           # MIDE físicamente respecto a la boquilla
y_offset: -10.0
#z_offset: 1.5            # lo escribe PROBE_CALIBRATE -> SAVE_CONFIG
samples: 2
samples_tolerance: 0.05

[safe_z_home]
home_xy_position: 140, 140   # centro de TU cama
speed: 50
z_hop: 10
z_hop_speed: 5
```
> Problema en el CNC: el ATmega328P tiene **pocos pines libres**. El BLTouch necesita 2 (señal + servo
> PWM). Si no quedan, valora ponerlo en la K10... pero entonces es **probing multi-MCU** (latencia) — no
> ideal. Mejor liberar pines (p.ej. no usar spindle) o ir a sonda de 1 hilo (inductiva/microswitch).
Pruebas: `BLTOUCH_DEBUG COMMAND=pin_down` / `pin_up` / `reset` / `self_test`.

### B) Sonda inductiva NPN (1 hilo de señal) — buena para frankenprinter con cama metálica
Detecta metal; **requiere cama/superficie metálica**. Muchas son de 12/24 V → **necesitas adaptar el
nivel** a 3.3/5 V (divisor resistivo o transistor) para no quemar el pin del MCU.
```ini
[probe]
pin: ^PB3                 # NPN open-collector: pull-up; añade ! si aparece invertido (^!PB3)
x_offset: 20.0
y_offset: 0.0
#z_offset: 0.8            # por PROBE_CALIBRATE
speed: 5.0
samples: 2
samples_result: median
sample_retract_dist: 2.0
```

### C) Microswitch en soporte (mecánico, 1 hilo, barato)
Un final de carrera montado junto a la boquilla, baja y toca la cama.
```ini
[probe]
pin: ^PB3                 # NC o NO -> ajusta con ! según el caso
x_offset: 0.0
y_offset: 25.0
#z_offset: ...
speed: 5.0
samples: 3
```

### D) Sonda piezo (detecta el toque de la propia boquilla) — offsets 0
```ini
[probe]
pin: ^PB3                 # salida del módulo piezo (comparador)
x_offset: 0.0
y_offset: 0.0
#z_offset: 0.0
speed: 3.0
samples: 3
samples_tolerance: 0.03
```

---

## Homing de Z con sonda

Para que la sonda haga de endstop de Z, en `[stepper_z]`:
```ini
endstop_pin: probe:z_virtual_endstop     # en vez de un endstop físico
# y ELIMINA position_endstop
```
Y añade `[safe_z_home]` (sube Z, homea XY, va al centro, homea Z). Si usas **endstop Z físico**
(microswitch fijo) en lugar de sonda, mantén `endstop_pin: ^PB4` y `position_endstop`.

---

## Calibrar z_offset (común a todas las sondas)

1. `G28` y lleva el cabezal cerca del centro.
2. `PROBE_CALIBRATE` → sondea y te deja bajar a mano con `TESTZ Z=-0.1`, `TESTZ Z=+0.05`… hasta que un
   papel roce la boquilla. `ACCEPT` y `SAVE_CONFIG` escribe el `z_offset`.
   - Con endstop Z mecánico (sin sonda): el equivalente es `Z_ENDSTOP_CALIBRATE`.

---

## Bed mesh (compensación de cama)

Primero el `z_offset` debe estar calibrado.
```ini
[bed_mesh]
speed: 120
horizontal_move_z: 5
mesh_min: 20, 20            # ajusta al alcance real de la sonda en TU volumen
mesh_max: 260, 260
probe_count: 5, 5
algorithm: bicubic
```
```
BED_MESH_CALIBRATE
SAVE_CONFIG
```
Carga la malla en cada impresión añadiendo `BED_MESH_PROFILE LOAD=default` a tu macro `PRINT_START`.

---

## Otros sensores que puedes añadir

- **Final de carrera de filamento** (`[filament_switch_sensor]`) para pausar al acabarse el filamento.
- **Termistor de cama** si añades cama caliente (otro MOSFET + ADC).
- **ADXL345** para input shaping ([08](08-calibracion.md)).
- **Endstops de Z dobles / Z-tilt** solo si pones 2 motores Z (deben ir en el **mismo MCU**).

Fuentes: <https://www.klipper3d.org/BLTouch.html> · <https://www.klipper3d.org/Probe_Calibrate.html> ·
<https://www.klipper3d.org/Bed_Mesh.html> · <https://www.klipper3d.org/Config_Reference.html>

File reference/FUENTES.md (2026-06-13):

# Fuentes y referencias (investigación 2026-06-11)

## Hardware EasyThreed K9 / K10
- **Reversing placa K10 (fuente técnica clave)** — GD32F303, USB-C solo PD, HR4988, MOSFET HY1403, SWD:
  https://palmarci.me/blog/2025-05-02-easythreed-k10-3d-printer-main-board-reversing/index.html
- Hackaday K9 (identifica MCU AT32F403ARCT7, 240 MHz):
  https://hackaday.com/2024/02/12/easythreed-k9-the-value-in-a-e72-aliexpress-fdm-3d-printer/
- Marlin comunitario EasyThreed (ECF-Marlin) — referencia de pinout:
  https://github.com/schmttc/ECF-Marlin
- Firmware K9 STM32:
  https://github.com/armandioan/EasyThreeD-K9-STM32 · https://github.com/jonylentzmc/EasyThreeD-K9-STM32-WIP-

## Klipper en GD32F303 (chip de la K10)
- Discourse: instalar Klipper en placas GD32F303 (compilar como STM32F103 + 28KiB + Disable SWD):
  https://klipper.discourse.group/t/installing-klipper-on-ender-3-4-2-2-board-and-gd32f303-chip/8165
- Issue Klipper GD32F303:
  https://github.com/Klipper3d/klipper/issues/5537

## Klipper en Arduino Uno + CNC Shield V3
- klipper-drawbot (montaje idéntico, config de referencia) — clonado en repos/:
  https://github.com/gwisp2/klipper-drawbot
- Benchmarks Klipper (límites step-rate AVR):
  https://www.klipper3d.org/Benchmarks.html
- GRBL cpu_map atmega328p (pinout autoritativo CNC Shield):
  https://github.com/grbl/grbl/blob/master/grbl/cpu_map/cpu_map_atmega328p.h
- Bootloaders (flasheo avrdude):
  https://www.klipper3d.org/Bootloaders.html

## Klipper general (docs oficiales)
- Config reference (multi-MCU, extruder, probe, bed_mesh):
  https://www.klipper3d.org/Config_Reference.html
- Multi-MCU homing:
  https://www.klipper3d.org/Multi_MCU_Homing.html
- Rotation distance:
  https://www.klipper3d.org/Rotation_Distance.html
- Config checks (PID, STEPPER_BUZZ):
  https://www.klipper3d.org/Config_checks.html
- Resonance / input shaping:
  https://www.klipper3d.org/Resonance_Compensation.html · https://www.klipper3d.org/Measuring_Resonances.html
- BLTouch / Probe / Bed mesh:
  https://www.klipper3d.org/BLTouch.html · https://www.klipper3d.org/Probe_Calibrate.html · https://www.klipper3d.org/Bed_Mesh.html
- Instalación / RPi como MCU:
  https://www.klipper3d.org/Installation.html · https://www.klipper3d.org/RPi_microcontroller.html

## Host / interfaces
- KIAUH (instalador) — clonado en repos/: https://github.com/dw-0/kiauh
- Moonraker — clonado en repos/: https://github.com/Arksine/moonraker
- Mainsail: https://github.com/mainsail-crew/mainsail · https://docs.mainsail.xyz/setup/kiauh/
- Fluidd: https://github.com/fluidd-core/fluidd

## Incertidumbres registradas (verificar físicamente)
- Encapsulado exacto del GD32 (RCT6/LQFP48 vs LQFP64): contar pines en TU placa.
- Voltaje del sistema K10/K9 (12V vs 24V): medir.
- Tipo exacto de termistor de la K10 (`sensor_type`): validar por lectura.
- Pinout completo K10 (drivers, heater, ADC, fan): NO publicado → reversing (docs/10).
- USART libre en la K10 (PA9/PA10 vs PA2/PA3 vs PB10/PB11): confirmar en reversing.
- Pin Z-endstop de TU CNC Shield (PB4 vs PB3): verificar con multímetro.

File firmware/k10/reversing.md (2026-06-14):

# Reversing del firmware OEM de la K10 — parámetros extraídos

Datos obtenidos del firmware de fábrica (`stock/p10_printer.bin` + `stock/k10_cfg.txt`),
no derivados a mano. Fuente del binario: reversing de palmarci (ver [stock/README.md](stock/README.md)).

## 1. Parámetros mecánicos/térmicos (de `k10_cfg.txt`, texto plano) — COMPLETO

| Parámetro | X | Y | Z | E |
|---|---|---|---|---|
| **steps/mm** | 606 | 606 | 600 | 1040 |
| corriente (mA) | 700 | 700 | 800 | 800 |
| feedrate máx (mm/s) | 20 | 20 | 20 | 20 |
| acel. máx | 50 | 50 | 50 | 100 |
| jerk | 2 | 2 | 0.4 | 0.5 |
| dir invertida | 1 | 1 | 1 | 1 |

- Volumen: **100 × 100 × 100 mm** (X/Y/Z min=0, max=100)
- Homing: **X→MIN (-1), Y→MAX (+1), Z→MIN (-1)**; feedrate homing 1800 mm/m
- Acel. global/retract/travel = 1000; XY jerk = 2
- Térmico: `EXTRUDE_MINTEMP=170`, `HEATER_0_MAXTEMP=275`
- **PID hotend: Kp=22.2, Ki=1.08, Kd=114**
- Thermal runaway: period 40 s, hyst 4 °C; watch 20 s / 2 °C
- Filament change: X5 Y5, Z lift +5

## 2. Acciones de botones (blog palmarci + G-code embebido en el binario) — COMPLETO

| Botón | Función | Secuencia G-code |
|---|---|---|
| S3 | Retract / descargar | `M104 S200` → `G1 E-120 F300` → `M104 S0` |
| S4 | Feed / cargar | `M104 S200` → `G1 E120 F120` → `G1 E20 F120` |
| S5 | Print / Lift | `M23 <archivo>` → `M24` · lift `G1 Z+10 F1000` |
| S6–S9 | Posición 1–4 | `G28` + movimientos (`G1 X20 Y20 … X80 Y80`) |

## 3. Pines GPIO — mapeo por reversing multi-agente (38 agentes, 5 lentes + verificación)

Desensamblado Thumb del firmware OEM + verificación adversarial pin a pin.
**⚠️ El binario es de la placa de palmarci (RCT6/LQFP64/256KB); esta placa es CBT6/LQFP48/128KB.
El enrutado de pines PUEDE diferir entre variantes. Confirmar lo crítico en la placa real.**

### ALTA confianza (consistente en varias lentes)

| Pin | Función | Notas |
|-----|---|---|
| **PA2** | **Termistor hotend** (ADC1_IN2) | único pin analógico → sin cama caliente |
| **PA3** | **Endstop** (input pull-up, polled) | hay **un solo** endstop discreto, no 3; eje sin confirmar |
| **PA5 / PA6 / PA7** | **SPI1** SCK / MISO / MOSI | display/lector SD. OJO: PA6 es MISO, **no** un endstop |
| **PB0,PB1,PB10,PB12,PB13,PB14,PB15** | **Teclado 7 botones** (S3–S9) | pull-up + EXTI; nº de botón concreto sin resolver |
| **PB4 / PB5** | PWM TIM3 (remap parcial) CH1/CH2 | fan/heater (etiqueta tentativa) |
| **PB6 / PB7 / PB8** | PWM TIM4 CH1/CH2/CH3 | fan/heater (etiqueta tentativa) |
| **PA13 / PA14** | SWD (SWDIO/SWCLK) | **no reasignar** |

### MEDIA confianza — STEPPERS (candidatos; eje X/Y/Z/E NO determinable)

La ISR analizada es una rutina de **test que mueve los 4 ejes a la vez**, así que se distingue
STEP vs DIR pero **no** qué eje es cada uno.

| Grupo | Pines candidatos |
|---|---|
| **STEP** (rápido) | PC15, PC13, PA9, **PA11** |
| **DIR** (lento) | PC14, PA8, PA10, **PA12** |
| **ENABLE** (LOW al boot, activo-bajo HR4988) | PB3, PA1 |
| Aux estáticos (enable/select/sleep?) | PA4, PA15, PB9 |

*La verificación adversarial refutó PA9=STEP y PC14=DIR → el grupo stepper es el menos fiable.*

### SIN RESOLVER (crítico)

- **🔴 Pin del HEATER del hotend.** Es **software-PWM** sobre un GPIO seleccionado desde una
  tabla en RAM (`@0x20000754`/`@0x2000079c`, offset 0x2c) → no se resolvió a un pin literal.
  Candidatos: PA4 / PA15 / PB9 o uno de los PWM. **Es el dato más importante que falta** (seguridad).
- **Eje** de cada stepper (X/Y/Z/E).
- **Etiqueta fan vs heater** de los 5 canales PWM (CCR escrito por punteros en runtime).

### 🔴 ALERTA para el plan Klipper — PA11/PA12

El firmware OEM usa **PA11/PA12 (las patas del USB D-/D+) como STEP/DIR de stepper**. Pero
**tu USB de Klipper soldado ahí FUNCIONA** (enumera y comunica). La explicación más probable:
tu placa CBT6/LQFP48 tiene un layout distinto al RCT6/LQFP64 de palmarci, y/o el grupo stepper
del análisis (rutina de test) no aplica a tu placa. **Conclusión práctica:** en TU placa,
PA11/PA12 = tu USB Klipper. No los uses para steppers en el `printer.cfg`.

## Equivalencia rápida a Klipper (lo ya listo)

```ini
[stepper_x]
rotation_distance: <full_steps*microsteps / 606>   # steps/mm = 606
# ... (microstepping de los HR4988 por confirmar; típico 1/16)
[extruder]
# rotation_distance a partir de 1040 steps/mm
control: pid
pid_Kp: 22.2
pid_Ki: 1.08
pid_Kd: 114
min_extrude_temp: 170
max_temp: 275
```

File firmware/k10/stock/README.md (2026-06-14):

# Firmware original (OEM) de la EasyThreed K10 — RESPALDO

Restauración de fábrica para volver atrás desde Klipper. **Los binarios NO se versionan**
aquí (firmware propietario de EasyThreed); este README es el puntero a la fuente original
y los hashes para verificar lo que descargues.

## Fuente

Publicado por **palmarci** en su reversing de la placa K10. El propio fabricante le envió
la imagen OEM por email, y coincide **byte a byte** con su dump por SWD de la flash.

- Blog: <https://palmarci.me/blog/2025-05-02-easythreed-k10-3d-printer-main-board-reversing/index.html>
- `from_oem/p10_printer.bin` — firmware de aplicación OEM (lo que va en `0x4000`)
- `from_oem/k10_cfg.txt` — configuración OEM
- `dumps/flash.bin` — volcado completo de la flash (incluye bootloader + app + config)
- `dumps/bl.dump` — bootloader

Descargar con, p. ej.:
```bash
BASE=https://palmarci.me/blog/2025-05-02-easythreed-k10-3d-printer-main-board-reversing
curl -fsSL "$BASE/from_oem/p10_printer.bin" -o p10_printer.bin
curl -fsSL "$BASE/from_oem/k10_cfg.txt"      -o k10_cfg.txt
```

## Hashes (verificación)

| Fichero | Tamaño | SHA256 |
|---|---|---|
| `p10_printer.bin` (OEM app) | 102 083 B | `01ac861d9e81b64623391010f088e87fb8bfdb0a60eae364de903c4a6666f25f` |
| `flash.bin` (dump completo) | 262 144 B | `c41b35850bde8c5777c880316e7faa27b033b7bfcd0c08b72e791419200138bb` |
| `bl.dump` (bootloader) | 18 432 B | `0de376cfd0eb81c479f696fcd719ed7ccfe33ea5a724c7da244101b259169e34` |

Verificado: `p10_printer.bin` == `flash.bin[0x4000 : 0x4000+102083]` (byte a byte).

## Cómo restaurar de fábrica (microSD)

1. Copia `p10_printer.bin` (OEM) a la **raíz** de una microSD FAT32.
   - Opcional: copia también `k10_cfg.txt` para restaurar la config de fábrica.
2. Placa apagada → mete la SD → enciende → espera ~10–30 s.
3. Si el fichero pasa a `p10_printer.CUR`, se restauró. El firmware EasyThreed vuelve a estar activo.

## Nota sobre el tamaño del chip

El dump de palmarci es de un chip de **256 KB** (`flash.bin` = 256 KB; su placa montaba el
`GD32F303RCT6`). Esta placa monta el **`GD32F303CBT6` (128 KB)**, pero la app OEM termina en
115.7 KB y la config en 126 KB, así que **cabe**. Es el mismo modelo de impresora; el riesgo de
incompatibilidad es bajo, pero queda anotado por transparencia.

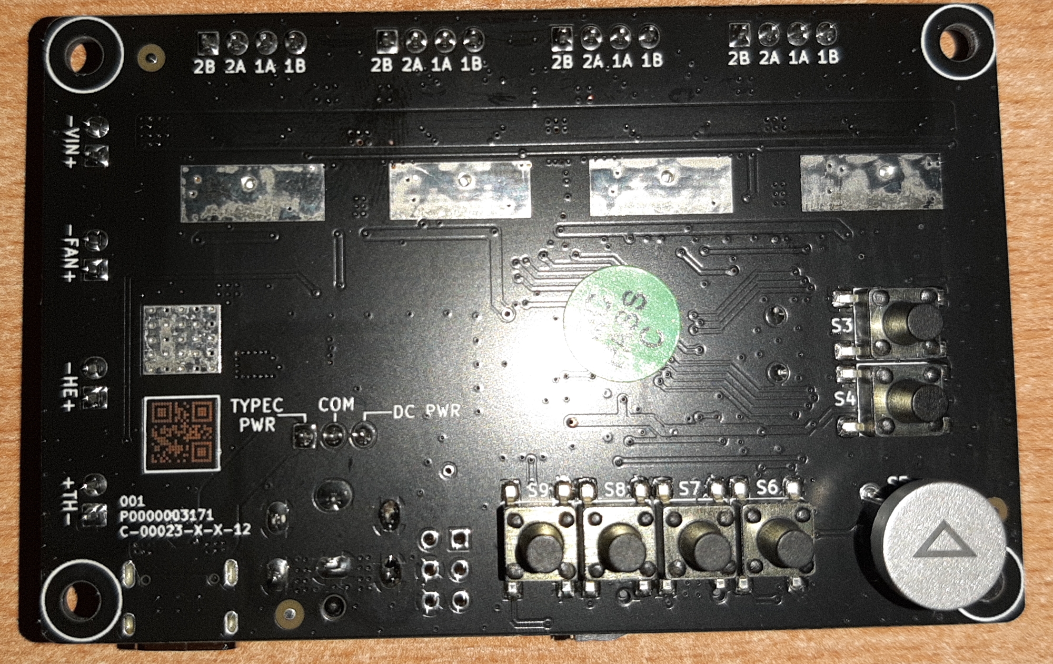
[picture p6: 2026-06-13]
reference/images/k10-placa-back.jpg

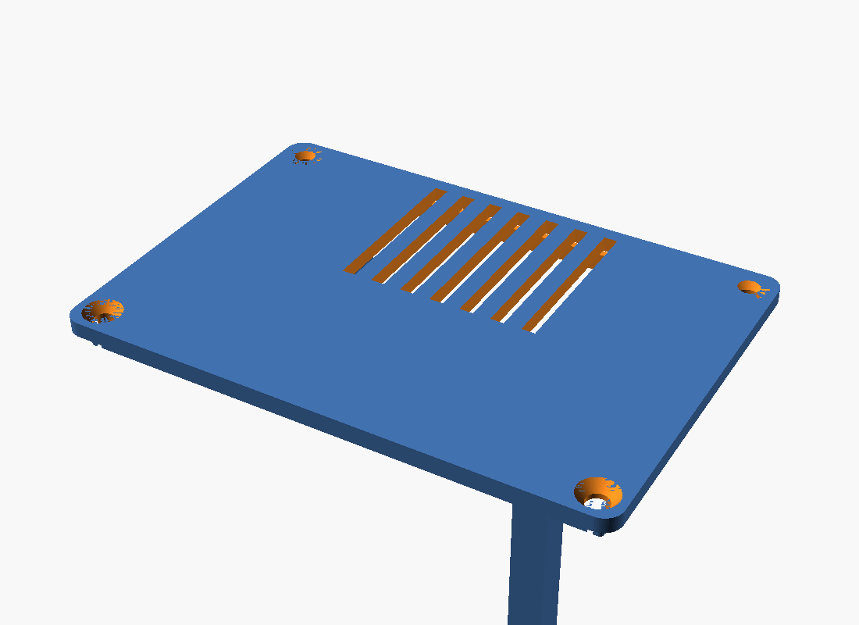
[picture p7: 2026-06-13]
cad/renders/k10_lid.png

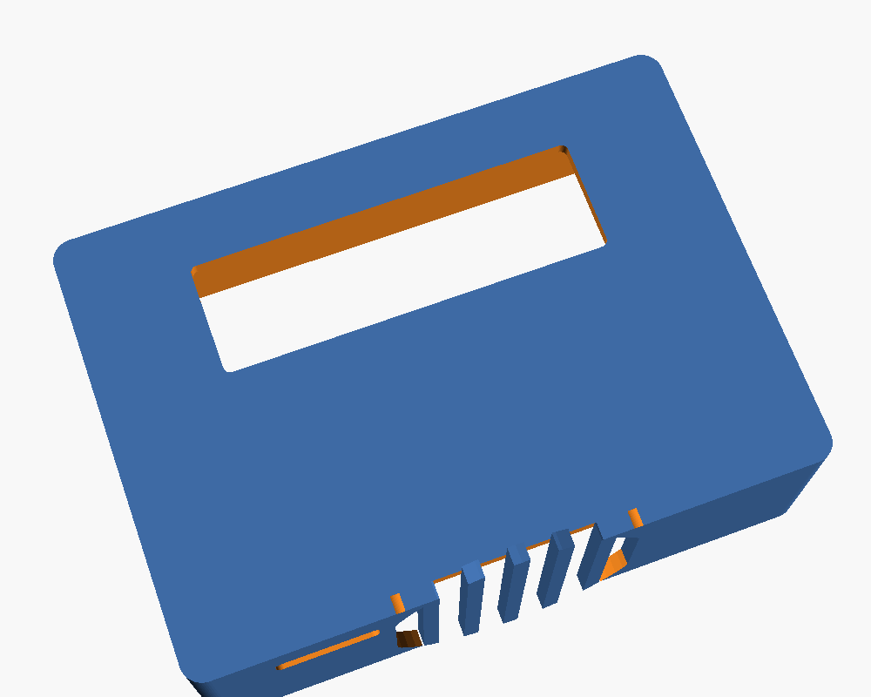
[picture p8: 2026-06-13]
cad/renders/k10_body_bottom.png

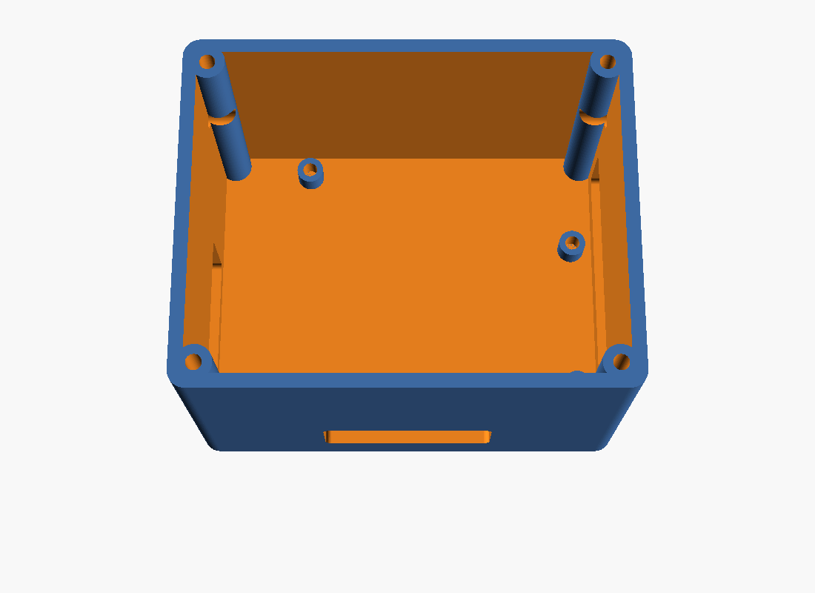
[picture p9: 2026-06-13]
cad/renders/uno_body_top.png

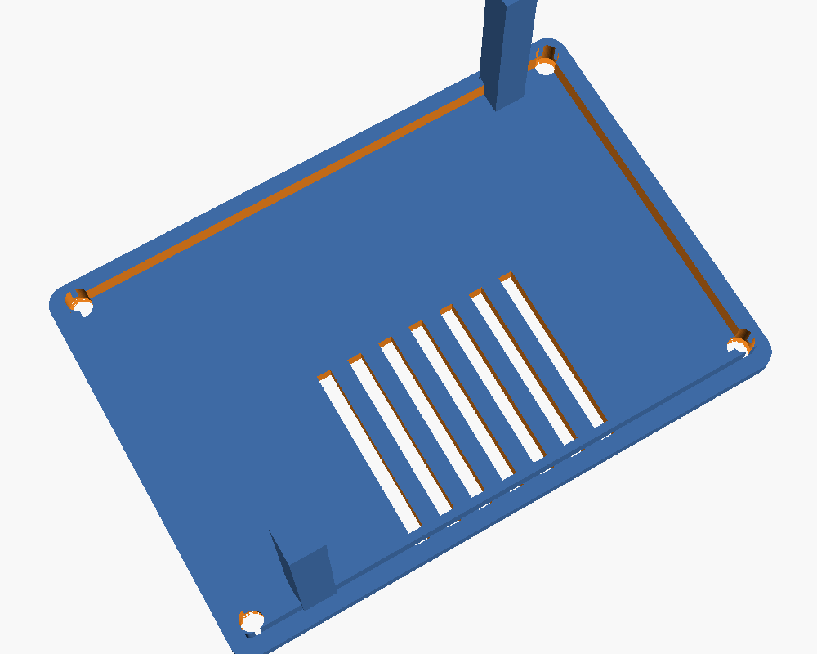
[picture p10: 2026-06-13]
cad/renders/k10_lid_under.png

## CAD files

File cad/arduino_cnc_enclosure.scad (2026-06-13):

// ============================================================================
//  arduino_cnc_enclosure.scad — Caja para Arduino Uno + CNC Shield V3 (MCU CNC)
//  Usa lib/enclosure_lib.scad. Unidades: mm. Imprimible en K9 (<=100mm), PETG.
//
//  El Arduino Uno tiene footprint ESTÁNDAR (no estimado):
//    board 68.6 x 53.4 mm, 4 agujeros M3 (Ø3.2). Coords oficiales (Adafruit/Arduino).
//  El CNC Shield se apila sobre el Uno por los headers; los drivers A4988/DRV8825
//  calientan -> ventilador en la tapa soplando hacia abajo sobre los drivers.
// ============================================================================

include <lib/enclosure_lib.scad>

part = "assembly";   // "body" | "lid" | "assembly"

// -------- Arduino Uno (estándar) --------
UNO_L = 68.6;
UNO_W = 53.4;
UNO_T = 1.6;
// 4 agujeros oficiales, origen esquina -> recentrados al centro del board:
//  A(13.97,2.54) B(66.04,7.62) C(66.04,35.56) D(15.24,50.80) menos (34.29,26.67)
UNO_HOLES = [[-20.32,-24.13],[31.75,-19.05],[31.75,8.89],[-19.05,24.13]];

// -------- Alturas del stack --------
// Uno + headers + CNC Shield + drivers con disipador + holgura/ventilación.
STANDOFF_H = 4;      // separación Uno<->suelo (pines/soldadura por debajo)
COMP_H     = 40;     // alto libre sobre el Uno: stack shield+drivers + flujo de aire

// -------- Caja --------
WALL=2.4; FLOOR=2.0; RAD=3; GAP=1.5;
LID_FAN = 50;        // ventilador PC en la tapa sobre los drivers (50mm)

IL = UNO_L + 2*GAP;
IW = UNO_W + 2*GAP;
IH = STANDOFF_H + UNO_T + COMP_H;
INNER=[IL,IW,IH];
PCB_Z = FLOOR + STANDOFF_H;
cable_z = PCB_Z + 6;

module uno_body() {
    union() {
        difference() {
            enclosure_body(INNER, wall=WALL, floor=FLOOR, rad=RAD,
                           pcb_holes=UNO_HOLES, standoff_h=STANDOFF_H,
                           lid_boss_mode="tap", chamfer_bottom=0);
            // USB-B + jack DC del Uno (borde IZQUIERDO -X): abertura generosa
            // (ambos conectores van en este borde; ajustar si tu clon difiere)
            port_rect(INNER, WALL, "left", 30, 13, pos=-10, zc=PCB_Z+5);
            // Salida de cables de motores/endstops del shield (borde DERECHO +X)
            port_rect(INNER, WALL, "right", 44, 12, pos=0, zc=cable_z);
            // Salida extra de cables (borde TRASERO -Y): endstops/spindle
            port_rect(INNER, WALL, "back", 30, 10, pos=0, zc=cable_z);
            // Acoplamiento lateral con otras cajas (tornillo+tuerca M3)
            couple_holes(INNER, WALL);
        }
    }
}

ARDU_LID_VENTS = true;

if (part=="body") uno_body();
if (part=="lid")
    enclosure_lid(INNER, wall=WALL, rad=RAD, thick=2.4, fan=LID_FAN, vents=ARDU_LID_VENTS);
if (part=="assembly") {
    uno_body();
    color("LightSteelBlue",0.85)
        translate([0,0, FLOOR+IH+2.4 + 14])
            enclosure_lid(INNER, wall=WALL, rad=RAD, thick=2.4, fan=LID_FAN, vents=ARDU_LID_VENTS);
}

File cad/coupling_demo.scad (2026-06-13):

// ============================================================================
//  coupling_demo.scad — Verificación visual del acople lateral entre cajas
//  Coloca la caja K10 y la del Arduino contiguas y comprueba que los agujeros
//  de acople (y=±24, z=30) alinean para pasar un tornillo M3 + tuerca.
//  (Demo con cascarones simplificados; las cajas reales están en sus .scad.)
// ============================================================================
include <lib/enclosure_lib.scad>
FLOOR=2; WALL=2.4;

module shell(il, iw, h, label) {
    difference() {
        rbox(il+2*WALL, iw+2*WALL, h, 3);
        translate([0,0,FLOOR]) rbox(il, iw, h, 2);
        couple_holes([il,iw], WALL);     // mismos COUPLE_Z / COUPLE_YS que las cajas reales
    }
}

// Dimensiones interiores reales de cada caja
K10  = [82.0, 56.0, 39.6];     // IL, IW, H
UNO  = [71.6, 56.4, 47.6];

// Caras que se tocan: +X de la K10 con -X del Arduino
xA = K10[0]/2 + WALL;          // cara derecha exterior de la K10
xB = UNO[0]/2 + WALL;          // cara izquierda exterior del Arduino
gap = 0;                        // las cajas se tocan
shiftB = xA + xB + gap;

color("SteelBlue")  shell(K10[0],K10[1],K10[2], "K10");
translate([shiftB,0,0]) color("IndianRed") shell(UNO[0],UNO[1],UNO[2], "UNO");

// Tornillos M3 de acople (atraviesan las dos paredes que se tocan)
color("Gold")
for (y=COUPLE_YS)
    translate([xA-8, y, COUPLE_Z]) rotate([0,90,0]) cylinder(d=3, h=16, $fn=24);

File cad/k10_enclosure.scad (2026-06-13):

// ============================================================================
//  k10_enclosure.scad — Caja para la placa de la EasyThreed K10 (GD32F303)
//  Usa lib/enclosure_lib.scad. Unidades: mm.  Imprimible en K9 (<=100mm), PETG.
//  Sistema: 12 V / 60 W (confirmado por specs del producto).
//
//  ⚠️ COTAS ESTIMADAS de las fotos del reversing — VERIFICA con calibre y ajusta
//     PCB_*, posiciones de PUERTOS y de la VENTANA DE BOTONES (TODO-MEDIR).
//
//  Orientación del PCB (componentes hacia ARRIBA / tapa; botones hacia ABAJO / suelo):
//    - Borde TRASERO  (-Y): 4 conectores de motor (X/Y/Z/Extrusor)
//    - Borde IZQUIERDO(-X): jack DC 12V + USB-C (entradas de alimentación)
//    - Borde DERECHO  (+X): mazo del cabezal (HE calefactor + termistor + fan)
//    - Borde FRONTAL  (+Y): ranura microSD + ventilador de refrigeración (40mm)
//    - SUELO          (-Z): ventana de acceso a los botones (S3-S8 + botón ▲)
//    - TAPA           (+Z): rejilla de ventilación
// ============================================================================

include <lib/enclosure_lib.scad>

// -------- Render: "body" | "lid" | "assembly" --------
part = "assembly";

// -------- Parámetros de la placa K10 --------
// Medidos por FOTOGRAMETRÍA (escala anclada al MCU GD32F303 LQFP48 = 7.0 mm,
// verificado contando pines). Ver reference/medidas-fotogrametria.md.
PCB_L      = 84.2;   // MEDIDO con calibre
PCB_W      = 54.0;   // MEDIDO con calibre
PCB_T      = 1.6;    // MEDIDO
COMP_H     = 30;     // alto libre sobre el PCB: componente más alto = 10mm (medido)
                     //    + ~20mm de ventilación. Fijado a 30 mm (pedido del usuario).
// Patrón de agujeros: 4 esquinas, Ø3 mm, 77 x 47 mm centro-a-centro (MEDIDO con calibre).
HOLE_DX    = 38.5;   // = 77/2
HOLE_DY    = 23.5;   // = 47/2

// -------- Botones del reverso (TODO-MEDIR posiciones) --------
// La cara de soldadura lleva 8 botones: S3/S4 (lat. derecho), S5-S8 (fila inferior)
// y un botón redondo grande ▲ (play/imprimir). Sobresalen ~5mm del PCB hacia el suelo.
// En modo Klipper estos botones quedan INACTIVOS, pero se les deja holgura (no aplastar)
// y una ventana de acceso opcional por si usas el firmware Marlin de fábrica.
BTN_CLEAR    = 6;       // holgura bajo el PCB para el cuerpo de los botones (>= su altura)
BTN_ACCESS   = true;    // abrir ventana en el suelo para alcanzar los botones
BTN_WIN      = [54, 16];// TODO-MEDIR: [ancho, fondo] de la ventana del cluster inferior
BTN_WIN_OFF  = [0, -14];// TODO-MEDIR: desplazamiento [x,y] del centro de la ventana
FEET         = false;   // pies para levantar la caja (acceso a botones); false = mejor adhesión PETG
FEET_H       = 6;

// -------- Parámetros de caja --------
WALL       = 2.4;
FLOOR      = 2.0;
RAD        = 3;
SIDE_GAP   = 1.5;    // holgura lateral PCB<->pared
STANDOFF_H = max(4, BTN_CLEAR);   // separa el PCB del suelo (holgura para botones)
FAN        = 40;     // ventilador PC: 40/50/60 (40 cabe de sobra)
CHAMFER    = 0;      // chaflán inferior (0 = recto; usa brim en el slicer para PETG)

// Interior derivado
IL = PCB_L + 2*SIDE_GAP;
IW = PCB_W + 2*SIDE_GAP;
IH = STANDOFF_H + PCB_T + COMP_H;     // alto interior libre
INNER = [IL, IW, IH];
PCB_Z = FLOOR + STANDOFF_H;           // cota de la cara inferior del PCB

PCB_HOLES = [[-HOLE_DX,-HOLE_DY],[HOLE_DX,-HOLE_DY],[HOLE_DX,HOLE_DY],[-HOLE_DX,HOLE_DY]];

// ============================================================================
//  Cuerpo
// ============================================================================
// Orientación (vista cenital, componentes hacia la tapa):
//   +Y (back)  = 4 conectores de motor (X/Y/Z/Extrusor)
//   +X (right) = mazo VIN + FAN + HE(calefactor) + TH(termistor)
//   +Y... front (-Y... ojo: port_rect "front" = +Y. Aquí "front" lo uso como
//   el borde de usuario): microSD + USB-C(PD) + jack DC
//   -X (left)  = ventilador de refrigeración (sopla a través del PCB)
// Posiciones (pos, mm desde el centro del borde) medidas por fotogrametría
// (motores y microSD: confianza alta; USB-C/DC: aprox., afinar con calibre).
module k10_body() {
    fan_z   = FLOOR + IH*0.5;          // centro del ventilador (cara izquierda -X)
    cable_z = PCB_Z + 5;               // altura de salida de los mazos (nivel conectores)

    union() {
        difference() {
            // PCB montado por TORNILLO en sus 4 agujeros (patrón 77x47 mm, Ø3, medido)
            enclosure_body(INNER, wall=WALL, floor=FLOOR, rad=RAD,
                           pcb_holes=PCB_HOLES, standoff_h=STANDOFF_H,
                           lid_boss_mode="tap", chamfer_bottom=CHAMFER);

            // Ventilador de refrigeración en la cara IZQUIERDA (-X)
            translate([-IL/2-WALL/2, 0, fan_z]) rotate([0,0,90]) fan_cutout(FAN, WALL);

            // --- PUERTOS por borde ---
            // BACK (-Y... port_rect "back"): 4 motores en mazo ancho (x: -27,-11,+2,+16)
            port_rect(INNER, WALL, "back",  56, 9, pos=-5, zc=cable_z);
            // RIGHT (+X): mazo del cabezal/potencia VIN+FAN+HE+TH (apilados en Y)
            port_rect(INNER, WALL, "right", 40, 11, pos=0, zc=cable_z);
            // FRONT (+Y): microSD + USB-C(PD) + jack DC (cara de usuario)
            port_rect(INNER, WALL, "front", 14, 3.5, pos=-12, zc=PCB_Z-1);  // microSD
            port_rect(INNER, WALL, "front", 10, 6,   pos=+6,  zc=cable_z);   // USB-C (PD)
            port_rect(INNER, WALL, "front", 10, 9,   pos=+22, zc=cable_z);   // jack DC 12V
            // USB INDEPENDIENTE (Klipper + 5V): conector USB separado para
            // datos (D+/D- a PA12/PA11) y alimentar el MCU por 5V (a VIN del AMS1117).
            port_rect(INNER, WALL, "front", 13, 7,   pos=-32, zc=cable_z);   // USB extra

            // --- VENTANA DE ACCESO A BOTONES en el suelo ---
            if (BTN_ACCESS)
                translate([BTN_WIN_OFF[0], BTN_WIN_OFF[1], -EPS])
                    linear_extrude(FLOOR+2*EPS)
                        offset(r=1) square([BTN_WIN[0]-2, BTN_WIN[1]-2], center=true);

            // --- ACOPLAMIENTO lateral con otras cajas (tornillo+tuerca M3) ---
            couple_holes(INNER, WALL);
        }
        // rejilla del ventilador (cara izquierda)
        translate([-IL/2-WALL/2, 0, fan_z]) rotate([0,0,90]) fan_grille(FAN, WALL);

        // pies opcionales (para alcanzar los botones por debajo)
        if (FEET)
            for (sx=[-1,1], sy=[-1,1])
                translate([sx*(IL/2-4), sy*(IW/2-4), -FEET_H])
                    cylinder(d=8, h=FEET_H+EPS);
    }
}

// ============================================================================
//  Render
// ============================================================================
// PCB montado por tornillo en los 4 agujeros -> la tapa ya no necesita postes de sujeción
if (part=="body")  k10_body();
if (part=="lid")
    enclosure_lid(INNER, wall=WALL, rad=RAD, thick=2.4, vents=true);
if (part=="assembly") {
    k10_body();
    color("LightSteelBlue", 0.85)
        translate([0,0, FLOOR+IH+2.4 + 12])
            enclosure_lid(INNER, wall=WALL, rad=RAD, thick=2.4, vents=true);
}

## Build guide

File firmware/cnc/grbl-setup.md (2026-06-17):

# CNC con GRBL 1.1h (Arduino Uno + CNC Shield V3)

Modo **GRBL** del CNC (alternativa a la vía Klipper, ver [`klipper.config`](klipper.config) +
[`../../docs/11-estado-y-handoff.md`](../../docs/11-estado-y-handoff.md)).

## Compilación y flasheo

```bash
# fuente: gnea/grbl 1.1h en repos/grbl (gitignorado)
cd repos/grbl && make                       # -> grbl.hex (~30.7 KB, cabe justo en 32 KB)
avrdude -c arduino -p atmega328p -P /dev/ttyACM0 -b 115200 -D -U flash:w:grbl.hex:i
```

Banner al conectar (115200 baud): `Grbl 1.1h ['$' for help]`.

## Settings aplicados

| Setting | Valor | Motivo |
|---|---|---|
| `$130 / $131 / $132` | 380 / 360 / 40 | Área de trabajo X/Y 38×36 cm; recorrido Z 40 mm |
| `$20` (soft limits) | 0 | Sin endstops (requiere homing) |
| `$21` (hard limits) | 0 | Sin endstops |
| `$22` (homing) | 0 | Sin endstops → cero manual antes de cada trabajo |

**Doble motor Y**: por **hardware** (jumpers de clonado del eje A puestos en Y). GRBL ve 3 ejes;
el 2º motor Y lo mueve el socket A clonando la señal de Y.

## Motores (los 4, rotulados igual)

**STP-42D221-01 (= EM-284)**: NEMA17, **1.8°/paso = 200 pasos/vuelta**, unipolar 5 cables
(conectados como bipolar a los A4988), ~1 A/fase. Microstepping **1/16** → 200×16 = **3200 µpasos/vuelta**.

## steps/mm

| Eje | `$` | Valor | Estado | Notas |
|-----|-----|---|---|---|
| Eje | steps/mm | vel. máx (mm/min) | acel. (mm/s²) | estado |
|-----|----------|-------------------|---------------|--------|
| X | `$100`=**75.83** | `$110`=**10000** | `$120`=**1200** | valores = Y (mismo motor/polea). **Verificar recableado bipolar de X** |
| Y | `$101`=**75.83** | `$111`=**10000** | `$121`=**1200** | ✅ CALIBRADO <0.5%, motor recableado a bipolar |
| Z | `$102`=**2226** | `$112`=**200** | `$122`=**8** | ✅ CALIBRADO ±2%, dir invertida `$3=4` |

> El traqueteo y la pérdida de pasos a velocidad **se resolvieron al recablear el motor a bipolar**
> (antes, unipolar mal conectado, perdía 1.2% a F600). Ya bipolar, Y aguanta **10000 mm/min y
> 1200 mm/s² sin perder pasos** (verificado por test de ida-vuelta, vuelve al origen exacto).

### Tabla completa de settings GRBL

| `$` | Valor | Significado |
|-----|---|---|
| `$3` | 4 | invertir dirección (bit2 = Z) |
| `$20`/`$21`/`$22` | 0/0/0 | soft limits / hard limits / homing **OFF** (sin endstops) |
| `$100`/`$101`/`$102` | 75.83 / 75.83 / 2226 | steps/mm X/Y/Z |
| `$110`/`$111`/`$112` | 10000 / 10000 / 200 | velocidad máx X/Y/Z (mm/min) |
| `$120`/`$121`/`$122` | 1200 / 1200 / 8 | aceleración X/Y/Z (mm/s²) |
| `$130`/`$131`/`$132` | 380 / 360 / 40 | recorrido máx X/Y/Z (mm) |

> **Z** queda lento a propósito ($112=200, $122=8): tornillo de alto ratio (2225 steps/mm). Si se quiere
> más rápido, calibrar su velocidad/aceleración aparte. **X** hereda los valores de Y pero su motor debe
> estar recableado a bipolar y verificado (gira suave + mide bien) antes de fiarse del calibrado.

### Eje Z — calibrado (2026-06-16)

- **Dirección invertida**: `Z+` bajaba → `$3=4`.
- Avance real del tornillo ≈ **1.44 mm/vuelta** (NO 2 mm; la medida a ojo del paso engañaba). Calibrado
  empíricamente: 10 mm comandados → 9.8 mm reales → `$102 = 2226`.
- **Backlash ≈ 0.55 mm** al invertir sentido (GRBL 1.1 no lo compensa → tuerca anti-holgura o asumirlo).
- El Vref bajo causaba pérdida de pasos al subir; con **0.71 V** en el trimpot Z dejó de perderlos.

### Calibración empírica X/Y (pendiente)

1. Vref ajustado, margen para no chocar. `$J=G91 G21 X10 F400` (jog 10 mm).
2. Mide el desplazamiento **real**. `nuevo_$100 = $100_actual × (10 / real_mm)`. Repite.
3. Para precisión usa un recorrido largo (menos error relativo). Igual con Y (`$101`).
4. Si un eje va invertido, añádelo a la máscara `$3` (bit0=X, bit1=Y, bit2=Z).

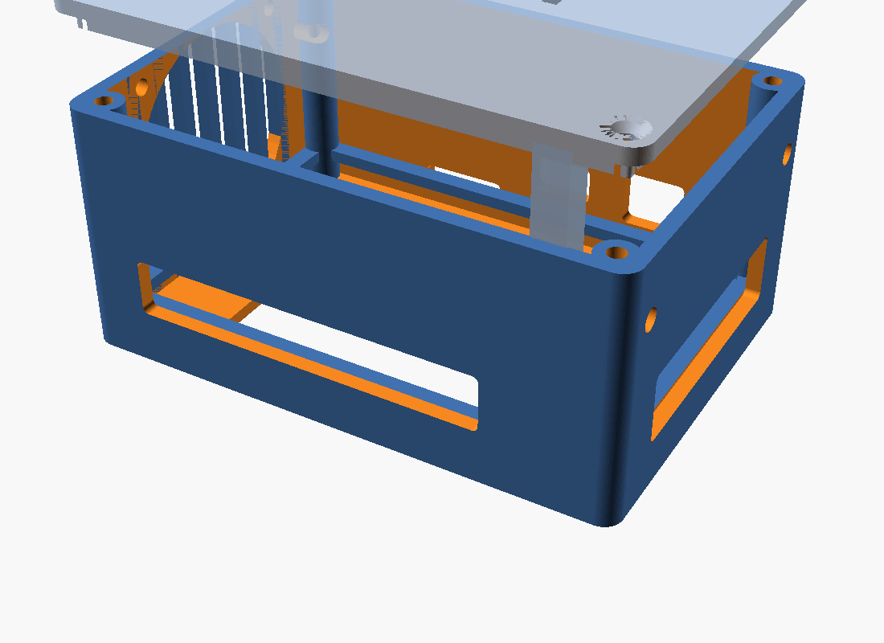
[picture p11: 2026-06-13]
cad/renders/k10_assembly.png

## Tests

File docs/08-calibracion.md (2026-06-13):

# 08 — Calibración

Orden recomendado: primero que **se mueva bien** (dirección + distancia), luego **térmica** (PID),
luego **extrusor**, y por último **input shaping**.

---

## 0. Antes de nada: comprobar cada motor

```
STEPPER_BUZZ STEPPER=stepper_x
```
Mueve 1 mm adelante/atrás 10 veces. Diagnóstico:
- **No se mueve** → revisa `enable_pin` / `step_pin` / Vref del driver.
- **No vuelve al origen / se va** → `dir_pin` invertido (añade o quita `!`).
- **Distancia no cuadra** → `rotation_distance` mal (siguiente sección).

Repite con `stepper_y`, `stepper_z`, `extruder`.

---

## 1. rotation_distance de X / Y / Z (mover y medir)

Klipper usa `rotation_distance`, no steps/mm. Para mecánica Epson reciclada (paso de correa/dientes
desconocidos) se calibra **experimentalmente**:

1. Pon un valor de partida en `[stepper_x]` (ej. `rotation_distance: 40`) y `FIRMWARE_RESTART`.
2. `G28` (homing). Marca con cinta la posición del carro; mide con regla/calibre desde un punto fijo.
3. Mueve una distancia grande conocida (más distancia = menos error relativo):
   ```
   G90
   G1 X100 F3000
   ```
4. Mide la distancia **real** recorrida (`medida`).
5. Corrige:
   ```
   rotation_distance_nuevo = rotation_distance_anterior × medida / 100
   ```
   Ej.: pediste 100, midió 96, partías de 40 → `40 × 96/100 = 38.4`.
6. Pon el nuevo valor, `FIRMWARE_RESTART`, y repite hasta que 100 pedidos = 100 ± 0.1 medidos.
7. Repite **independiente** para Y y para Z (en Z, mover en vertical y medir con calibre; husillo
   recuperado → mismo método).

> Mide siempre moviendo en la **misma dirección** para no contaminar con el backlash de los carros Epson.
> Cambiar `microsteps` NO cambia `rotation_distance` (esa es la gracia del modelo de Klipper).

---

## 2. PID del hotend (y cama si la tienes)

Requiere la K10 ya comunicando y el termistor leyendo bien (sección 4 más abajo para validarlo).
```
PID_CALIBRATE HEATER=extruder TARGET=210
SAVE_CONFIG
```
Cama (si lleva PWM):
```
PID_CALIBRATE HEATER=heater_bed TARGET=60
SAVE_CONFIG
```
`SAVE_CONFIG` reescribe los `pid_Kp/Ki/Kd` en un bloque autogenerado al final de `printer.cfg` y reinicia.
En `[extruder]` debe estar `control: pid`. Alternativa simple: `control: watermark` (bang-bang) sin calibrar.

---

## 3. rotation_distance del extrusor (measure & trim)

Con hotend **caliente** (>min_extrude_temp) y filamento cargado:
1. Marca el filamento a **70 mm** de la entrada del extrusor (mide con calibre).
2. ```
   G91
   G1 E50 F60        # extruye 50 mm lento
   ```
3. Mide de nuevo: `extruido_real = 70 − (lo que quedó)`.
4. Corrige:
   ```
   rotation_distance_nuevo = rotation_distance_anterior × extruido_real / 50
   ```
   Redondea a 3 decimales. Si la diferencia con 50 fue > 2 mm, repite tras corregir.

`max_extrude_only_distance: 50` por defecto; si purgas/cargas más de 50 mm de golpe, súbelo (100–150) o
dará "Extrude only move too long".

---

## 4. Validar el termistor de la K10

Como el `sensor_type` lo determinas por reversing, verifica que la lectura sea coherente:
- Con el hotend **frío**, debe marcar ≈ temperatura ambiente (20–25 °C). Si marca 0/−something o un valor
  absurdo, el `sensor_type` o el `sensor_pin` están mal.
- Tipos comunes a probar: `Generic 3950` (NTC 100k β=3950, el más habitual en clones) o
  `EPCOS 100K B57560G104F`. Cambia `sensor_type`, `RESTART`, y compara con un termómetro.
- `min_temp`/`max_temp` disparan **shutdown** si la lectura se sale: pon `min_temp: 0` y un `max_temp`
  seguro para tu hotend (250 con PTFE, 300+ all-metal).

---

## 5. Input shaping (anti-ringing)

### Con acelerómetro ADXL345 (recomendado)
Config (ADXL en la Pi por SPI):
```ini
[mcu rpi]
serial: /tmp/klipper_host_mcu

[adxl345]
cs_pin: rpi:None

[resonance_tester]
accel_chip: adxl345
probe_points: 140, 140, 20      # centro de TU cama (ajusta a tu volumen)
```
Comandos:
```
ACCELEROMETER_QUERY      # ¿responde? muestra X/Y/Z
MEASURE_AXES_NOISE       # ruido de fondo (debe ser bajo)
SHAPER_CALIBRATE         # mide ambos ejes y sugiere shaper+frecuencia
SAVE_CONFIG
```
Resultado típico:
```ini
[input_shaper]
shaper_freq_x: 49.4
shaper_type_x: mzv
shaper_freq_y: 42.0
shaper_type_y: mzv
```

### Sin acelerómetro (torre de ringing manual)
Imprime `~/klipper/docs/prints/ringing_tower.stl` (0 % relleno, 1–2 perímetros, 80–100 mm/s). Antes:
```
SET_VELOCITY_LIMIT MINIMUM_CRUISE_RATIO=0
SET_PRESSURE_ADVANCE ADVANCE=0
SET_INPUT_SHAPER SHAPER_FREQ_X=0 SHAPER_FREQ_Y=0
TUNING_TOWER COMMAND=SET_VELOCITY_LIMIT PARAMETER=ACCEL START=1500 STEP_DELTA=500 STEP_HEIGHT=5
```
Mide la distancia D entre picos de ringing y cuenta N oscilaciones: **f = V·N / D (Hz)** (V = velocidad
del perímetro). Prueba frecuencias con `SET_INPUT_SHAPER SHAPER_TYPE=mzv SHAPER_FREQ_X=...`.
Tipos: ZV, **MZV** (recomendado), ZVD, EI, 2HUMP_EI/3HUMP_EI.

> Recuerda el límite del ATmega328P: input shaping añade carga de pasos. Si aparece `Timer too close`,
> baja microsteps/aceleración.

---

## Resumen de comandos
| Tarea | Comando |
|---|---|
| Probar motor | `STEPPER_BUZZ STEPPER=stepper_x` |
| PID hotend | `PID_CALIBRATE HEATER=extruder TARGET=210` → `SAVE_CONFIG` |
| Extrusor | `G91` + `G1 E50 F60` (measure & trim) |
| z_offset sonda | `PROBE_CALIBRATE` → `TESTZ Z=±..` → `ACCEPT` → `SAVE_CONFIG` |
| Malla cama | `BED_MESH_CALIBRATE` → `SAVE_CONFIG` |
| Resonancias | `SHAPER_CALIBRATE` → `SAVE_CONFIG` |

Fuentes: <https://www.klipper3d.org/Rotation_Distance.html> · <https://www.klipper3d.org/Config_checks.html> ·
<https://www.klipper3d.org/Resonance_Compensation.html> · <https://www.klipper3d.org/Measuring_Resonances.html>

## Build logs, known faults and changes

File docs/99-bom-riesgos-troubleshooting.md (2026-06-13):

# 99 — BOM, riesgos y troubleshooting

## Lista de materiales (BOM)

### Ya tienes
- EasyThreed K10 (donante de cabezal: hotend, cartucho calefactor, termistor, motor extrusor, fan).
- CNC casero: Arduino Uno + CNC Shield V3 + drivers A4988/DRV8825 + 3× NEMA17 + mecánica Epson.
- EasyThreed K9 (se queda como está; no se toca).

### Necesario (común a todas las opciones)
| Item | Aprox. | Notas |
|---|---|---|
| Raspberry Pi (3B+/4/Zero 2W) + microSD ≥16 GB | 15–60 € | Host Klipper |
| Fuente 5 V / 3 A para la Pi | 8 € | Independiente de la potencia |
| Fuente de potencia motores (12–24 V, según drivers) | 10–20 € | Para la CNC Shield |
| Cableado, borneras, fundas | 10 € | |
| Sonda Z (microswitch / inductiva NPN / BLTouch) | 3–35 € | Ver [09](09-sensores-zprobe.md) |

### Específico Opción A (Klipper en la K10)
| Item | Aprox. | Notas |
|---|---|---|
| Adaptador USB-TTL **3.3 V** (FT232/CP2102/CH340) | 3–6 € | **Imprescindible 3.3 V** |
| ST-Link V2 (o Pi Pico como Picoprobe) | 3–8 € | Flasheo/volcado por SWD |
| Cable AWG30 + flux + estaño fino | 8 € | Microsoldadura UART |

### Específico Opción B/C (board dedicado para el cabezal)
| Item | Aprox. | Notas |
|---|---|---|
| Board Klipper-friendly (SKR Mini E3, MKS, o board GD32 Creality 4.2.2) | 15–40 € | Pinout conocido, sin reversing |

### Opcional (afinado)
- Acelerómetro **ADXL345** (~5 €) para input shaping medido.
- Sensor de fin de filamento (~3 €).

---

## Mapa de riesgos

| Riesgo | Prob. | Impacto | Mitigación |
|---|---|---|---|
| Reversing K10 se atasca (pin no localizable) | Media | Bloquea Opción A | Tener lista la Opción B como plan B; volcar firmware y usar pins de Marlin |
| Dañar el GD32 al soldar UART (5 V, ESD, calor) | Media | Pierdes la K10 | Adaptador 3.3 V; pulso de soldadura corto; pulsera antiestática; verificar pad antes |
| Térmica descontrolada (heater sin termistor validado) | Baja | **Peligro de fuego** | Validar termistor ANTES de permitir calentar; `min_temp/max_temp`; `verify_heater`; no dejar sin supervisión |
| `Timer too close` en ATmega328P | Media | Aborta impresión | microsteps ≤ 1/16; bajar accel/velocidad; no recargar el AVR de extras |
| Volumen Z bajo (~70 mm) | Alta | Limita piezas altas | Diseñar bancada para maximizar Z; asumir piezas bajas; o rediseñar eje Z |
| Mecánica Epson con backlash/holgura | Media | Calidad dimensional | Calibrar midiendo en una dirección; tensar correas; considerar antibacklash en Z |
| CH340 sin serie única (multi-MCU confunde puertos) | Media | Conecta MCU equivocado | `by-path` + puerto USB fijo |
| Masas no comunes | Media | Comms erráticas / ADC ruidoso | Unir todos los GND |

### Seguridad eléctrica y térmica (no opcional)
- **GND común** entre Pi, Arduino, adaptador USB-TTL, K10 y fuentes.
- Señales al GD32 a **3.3 V** (UART/ADC). Adaptador USB-TTL en 3.3 V.
- Activa protecciones térmicas de Klipper: el `[extruder]` con `min_temp/max_temp` correctos, y considera
  `[verify_heater extruder]` (detecta calentamiento anómalo). Nunca dejes el primer calentamiento sin vigilar.
- Fusible/protección en la línea de potencia del calefactor y motores.

---

## Troubleshooting por síntoma

| Síntoma | Causa probable | Solución |
|---|---|---|
| `mcu 'k10': Unable to connect` | TX/RX cruzados, baud, sin GND común, no flasheado | Intercambiar TX/RX; mismo baud host/MCU; GND común; reflashear |
| `Unable to open serial port` | `serial:` incorrecto | `ls /dev/serial/by-id/*` y corregir; `by-path` si CH340 |
| `mcu 'mcu': Command request` / versiones distintas | host y MCU compilados de commits distintos | recompilar y reflashear ambos al mismo commit |
| Motor no se mueve | enable/step/Vref | `STEPPER_BUZZ`; subir Vref; revisar `enable_pin !` |
| Motor al revés | dir | añadir/quitar `!` en `dir_pin` |
| Eje mueve mal la distancia | rotation_distance | calibrar mover-y-medir ([08](08-calibracion.md)) |
| Un eje correcto, otro invertido | cableado bobinas | intercambiar conexión de drivers/motor o `!` dir |
| `ADC out of range` al arrancar | termistor mal/`sensor_pin` o `sensor_type` | validar termistor frío ≈ ambiente; probar otro `sensor_type` |
| Hotend no calienta / PID falla | heater_pin mal, fuente, cartucho | verificar `heater_pin` (doc 10); medir cartucho; PID_CALIBRATE |
| `Timer too close` / `Rescheduled timer in the past` | AVR saturado | bajar microsteps/accel/velocidad |
| `Move out of range` | position_min/max o homing | revisar límites y `position_endstop` |
| Homing Z impreciso (multi-MCU) | endstop/sonda en MCU distinto a steppers Z | poner sonda/endstop Z en el MCU del CNC |
| Web no carga | moonraker/nginx | `systemctl status moonraker`; revisar `cors`/`trusted_clients` en moonraker.conf |

### Logs útiles
```bash
journalctl -u klipper -f
journalctl -u moonraker -f
tail -f ~/printer_data/logs/klippy.log
```

---

## Hitos de validación (haz uno a uno, no todo de golpe)
1. [ ] Host: Mainsail abre y conecta con Moonraker.
2. [ ] CNC flasheado; `[mcu]` conecta; `STEPPER_BUZZ` mueve X/Y/Z.
3. [ ] Homing XYZ con endstops correcto.
4. [ ] rotation_distance XYZ calibrado (100 mm = 100 mm).
5. [ ] (A) K10 con UART + Klipper; `[mcu k10]` conecta.
6. [ ] Termistor K10 lee ambiente coherente.
7. [ ] heater_pin verificado; PID hotend.
8. [ ] Extrusor calibrado (measure & trim).
9. [ ] Sonda Z + z_offset + bed mesh.
10. [ ] Primera línea / primera capa de prueba.
11. [ ] Input shaping.

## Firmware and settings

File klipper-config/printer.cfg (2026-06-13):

# ============================================================================
#  printer.cfg — Frankenprinter K10 + CNC (Klipper multi-MCU)
#  Config de PARTIDA para experimentar. Lee docs/ antes de aplicar potencia.
#
#  Copia este archivo y la carpeta include/ a:  ~/printer_data/config/
#  Ajusta los 'serial:' (ls /dev/serial/by-id/*) y los pines marcados PARCHEAR.
# ============================================================================

# --- Módulos (cada uno comentado y documentado) ---
[include include/mcu-cnc.cfg]        # MCU principal: Arduino Uno + CNC Shield (XYZ)
[include include/steppers-xyz.cfg]   # Ejes X/Y/Z
[include include/extruder-hotend.cfg]# Cabezal: extrusor + hotend (MCU k10 u otro board)
#[include include/probe-zsensor.cfg] # Sonda Z (descomenta cuando la montes)
[include include/macros.cfg]         # Macros PRINT_START/END, etc.

# ============================================================================
#  Cinemática general de la impresora
# ============================================================================
[printer]
kinematics: cartesian
# Empieza CONSERVADOR. Sube cuando todo funcione y tras input shaping.
max_velocity: 150
max_accel: 1500
max_z_velocity: 10
max_z_accel: 100
# Recuerda el límite de step-rate del ATmega328P (ver docs/03). 1/16 microsteps.

# ============================================================================
#  Almacenamiento de G-code (lo sirve Moonraker/Mainsail)
# ============================================================================
[virtual_sdcard]
path: ~/printer_data/gcodes

[display_status]
[pause_resume]

# Soporte de arcos G2/G3 (útil si reaprovechas G-code de CNC)
[gcode_arcs]
resolution: 1.0

# ============================================================================
#  NOTA: tras PID_CALIBRATE / PROBE_CALIBRATE / SHAPER_CALIBRATE, Klipper
#  añade un bloque "#*# <---------------------- SAVE_CONFIG ---------------->"
#  al final de ESTE archivo. No lo edites a mano.
# ============================================================================

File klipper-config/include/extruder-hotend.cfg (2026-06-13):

# ============================================================================
#  extruder-hotend.cfg — Cabezal: extrusor + hotend
#
#  OPCIÓN A (fiel a tu idea): el cabezal lo gobierna la placa K10 (GD32F303)
#  como MCU secundario "k10". Los pines P?? se obtienen por REVERSING (docs/10).
#
#  OPCIÓN B/C: si usas un board dedicado, cambia el prefijo 'k10:' por el del
#  board (o quítalo si es el MCU principal) y pon sus pines reales.
# ============================================================================

# --- MCU secundario: placa K10. Comms segun la via elegida (docs/04, diagrams/k10-soldadura-usb.md) ---
[mcu k10]
# PARCHEAR segun la via:
#  Opcion A (USB nativo del GD32, recomendada) o C (USB-TTL):  ls /dev/serial/by-id/*
serial: /dev/serial/by-id/usb-Klipper_stm32f103xe_XXXXXXXXXXXX-if00
#  Opcion B (UART por GPIO de la Pi): comenta la linea de arriba y usa:
#serial: /dev/ttyAMA0

[extruder]
# --- Motor del extrusor (driver HR4988 de la K10) ---
step_pin: k10:PA0          # PARCHEAR (reversing, docs/10)
dir_pin: k10:PA1           # PARCHEAR  (añade '!' si invierte)
enable_pin: !k10:PA2       # PARCHEAR  (activo-bajo típico)
microsteps: 16
rotation_distance: 33.500  # PARCHEAR: calibrar measure & trim (docs/08)
full_steps_per_rotation: 200   # NEMA17 1.8° (usa 400 si es de 0.9°)
nozzle_diameter: 0.400     # PARCHEAR a tu boquilla
filament_diameter: 1.750

# --- Calefactor + termistor (MOSFET HY1403 + divisor del termistor) ---
heater_pin: k10:PB0        # PARCHEAR: gate del MOSFET (reversing, docs/10)
sensor_type: Generic 3950  # PARCHEAR: validar (Generic 3950 o EPCOS 100K B57560G104F)
sensor_pin: k10:PA3        # PARCHEAR: pin ADC del termistor (reversing)
control: pid               # tras PID_CALIBRATE -> SAVE_CONFIG reescribe Kp/Ki/Kd
pid_Kp: 22.2               # placeholder; lo sobrescribe PID_CALIBRATE
pid_Ki: 1.08
pid_Kd: 114.0
min_temp: 0                # < min_temp o > max_temp => SHUTDOWN de seguridad
max_temp: 250              # PARCHEAR según hotend (250 PTFE / 300+ all-metal)
min_extrude_temp: 170      # no extruye en frío
max_extrude_only_distance: 100.0   # sube si haces purgas/cargas largas

# Protección térmica recomendada (descomenta cuando el termistor esté validado):
#[verify_heater extruder]
#max_error: 120
#check_gain_time: 20
#hysteresis: 5
#heating_gain: 2

# --- Ventiladores ---
[fan]
# Fan de capa (pieza). PARCHEAR al pin del fan en la K10 (reversing).
pin: k10:PB1

#[heater_fan hotend_fan]
# Fan del disipador del hotend (si es controlable). Si va siempre a 12V fijo, omítelo.
#pin: k10:PB10
#heater: extruder
#heater_temp: 50.0

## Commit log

2026-06-13 Documentación inicial: frankenprinter K10 + CNC con Klipper
    Base de conocimiento y configuraciones de partida para fusionar el cabezal
    de una EasyThreed K10 (GD32F303) con un CNC casero (Arduino Uno + CNC Shield,
    NEMA17) en una máquina multifunción gobernada por Klipper multi-MCU.
    - docs/ 00-10 + 99: arquitectura, hardware K10/CNC, comunicación (USB nativo
    del GD32 / UART), flasheo, cableado, host Pi, calibración, sondas, reversing
    del pinout, BOM y troubleshooting.
    - diagrams/: arquitectura, pinout CNC Shield V3 y esquema eléctrico de
    soldadura USB (ASCII alineado verificado) con fotos reales de la placa.
    - klipper-config/: printer.cfg + includes (MCUs, steppers XYZ, extrusor/h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
    [extruder-hotend.cfg, macros.cfg, mcu-cnc.cfg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]
2026-06-13 cad: librería paramétrica OpenSCAD + caja K10 (watertight, imprimible K9)
    - lib/enclosure_lib.scad: módulos reutilizables (caja body/lid, bosses M3 con
    solape a pared, standoffs PCB, soporte de ventilador PC estándar con rejilla,
    acople cola de milano, recortes de puertos). Guard de 100mm para la K9.
    - k10_enclosure.scad: caja de la placa K10 con ventilador de pared, 4 puertos
    (USB-C/jack DC/mazo cabezal/microSD) y tapa atornillada M3 con ventilación.
    Cotas estimadas de las fotos (marcadas TODO-MEDIR).
    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
    [k10_enclosure.scad]
2026-06-13 cad: caja K10 con acceso a botones, bordes de puertos correctos y 12V
    - Layout de puertos por borde según reversing (verificado): motores atrás,
    DC+USB-C izquierda, mazo del cabezal derecha, microSD+ventilador frente.
    - Botones del reverso (S3/S4, S5-S8, botón redondo ▲): holgura bajo el PCB
    para no aplastarlos (standoffs >= altura botón) + ventana de acceso en el
    suelo (Klipper los deja inactivos; acceso opcional para firmware Marlin).
    - Confirmado sistema 12V/60W. Sigue watertight (87.8x62.8x37.1 < 100mm).
    - Render de la cara inferior añadido.
    Nota: las dimensiones reales del PCB K10 NO están publicadas en ninguna
    fuente (verificado: reversing, manuales, repuestos, modelos 3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
    [k10_enclosure.scad]
2026-06-13 cad: medidas de la K10 por fotogrametría (PCB 79x53 mm)
    Estimadas las cotas del PCB desde las fotos del reversing usando el MCU
    GD32F303 LQFP48 (cuerpo 7.0 mm, verificado contando pines ~12/lado) como
    regla de escala (0.0419 mm/px).
    - Contorno PCB: 79 x 53 mm (alta confianza +-2 mm; aspecto 1.50 por ambas caras).
    - Patron de agujeros ~72x44 mm c-a-c (confianza media +-2-3 mm) -> no fiar a ciegas,
    retencion por contorno + tapa; verificar con calibre.
    - Altura de componentes: no medible desde cenital -> COMP_H provisional 17 mm.
    - k10_enclosure.scad actualizado con las medidas; sigue watertight.
    - reference/medidas-fotogrametria.md: metodo, referencias y confianza.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
    [k10_enclosure.scad]
2026-06-13 cad: K10 altura libre 30mm (componentes + ventilacion); sockets DC/USB-C/microSD
    - COMP_H=30: holgura sobre el PCB que cubre el componente mas alto y deja
    hueco de flujo de aire para el ventilador. Body 86.8x60.8x39.6 mm (<100, K9 OK).
    - Confirmados los 3 sockets de usuario: jack DC + USB-C (PD) en cara lateral,
    ranura microSD en cara frontal junto al ventilador de 40mm.
    - Sigue watertight. Render de puertos anadido.
    [k10_enclosure.scad]
2026-06-13 cad: K10 retencion del PCB por contorno + puertos reorientados (A+B)
    A) Orientacion y puertos segun fotogrametria/etiquetas: motores (back),
    mazo VIN/FAN/HE/TH (right), microSD+USB-C+DC (front), ventilador 40mm (left).
    B) Retencion del PCB sin depender de los agujeros:
    - pcb_ledge: repisa perimetral de apoyo (usa el contorno 79x53, fiable).
    - lid_holddown: 2 postes en la tapa que presionan el margen del PCB.
    - Quitados los standoffs por agujero (PCB_HOLES ya no se usan para montaje).
    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
    [k10_enclosure.scad]
2026-06-13 cad: caja Arduino Uno + CNC Shield (C) + fix ventilador de tapa
    - arduino_cnc_enclosure.scad: caja para el stack Uno+CNC Shield V3.
    Footprint Uno estandar (68.6x53.4) con los 4 agujeros oficiales M3 como
    standoffs (montaje por tornillo, patron conocido). COMP_H=40 para shield+
    drivers+ventilacion. Ventilador 50mm en la tapa sobre los drivers.
    Aberturas: USB-B/jack (izq), cables motores (der) y endstops (atras).
    Body 76.4x61.2x47.6, watertight, <100mm (K9 OK).
    - FIX lib: el ventilador de la TAPA tenia un rotate([90,0,0]) erroneo que lo
    orientaba de lado; corregido (fan_cutout_flat/grille_flat van planos en Z).
    - build.sh genera tambien las piezas del Arduino.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
    [arduino_cnc_enclosure.scad]
2026-06-13 cad: acople lateral entre cajas (D) + README actualizado
    D) Acoplamiento entre cajas por tornillo lateral M3:
    - lib couple_holes(): agujeros M3 pasantes a z=30 y y=+-24 (constantes
    COUPLE_Z/COUPLE_YS), en pared maciza comun a todas las cajas. Encadenable.
    - Anadidos a la K10 y a la caja Arduino; ambas siguen watertight.
    - coupling_demo.scad: verifica que los agujeros alinean entre las dos cajas
    contiguas (render coupling_demo.png).
    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
    [arduino_cnc_enclosure.scad, coupling_demo.scad, k10_enclosure.scad]
2026-06-13 cad: K10 con medidas reales de calibre + montaje por tornillo + USB extra
    Medidas reales (calibre del usuario):
    - PCB 84.2 x 54.0 x 1.6 mm (la fotogrametria daba 79x53; corregido).
    - Agujeros Ø3, patron 77 x 47 mm centro-a-centro (HOLE_DX/DY=38.5/23.5).
    - Componente mas alto 10 mm (COMP_H=30 se mantiene: 10mm + ventilacion).
    Cambios:
    - Montaje del PCB por TORNILLO en los 4 agujeros (quitada la repisa/postes de
    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
    [k10_enclosure.scad]
2026-06-13 docs: alimentar K10 por USB 5V independiente con proteccion + guia visual
    - reference/alimentacion-usb-5v.md: inyectar 5V en el VIN del AMS1117 (carril
    de ~5V que alimenta la logica 3.3V). Identificacion del pin VIN con multimetro.
    Cadena de proteccion: polyfuse 500mA + Schottky (anti-inversa/backfeed) +
    TVS 5.6V + 10uF. Cableado completo del USB (5V/D+/D-/GND) para Klipper+power.
    - reference/images/k10-usb-solder-guide.jpg: foto anotada con los puntos.
2026-06-14 firmware: CI para compilar Klipper de la K10 (GD32F303CBT6) + flasheo SD p10_printer.bin
    - .github/workflows/build-k10-klipper.yml: compila Klipper en la nube (toolchain ARM
    en runner), verifica enlace en 0x08004000 y publica p10_printer.bin como artefacto.
    - firmware/k10/klipper.config: config minima (STM32F103 + Disable SWD GigaDevice +
    USB PA11/PA12 + bootloader 16KiB + cristal 8MHz), validada con make olddefconfig.
    - firmware/k10/README.md: parametros del MCU y procedimiento de flasheo por microSD.
    - diagrams/k10-soldadura-usb.md: seccion 6 (bootloader real K10: p10_printer.bin @0x4000,
    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
2026-06-14 docs: puntero al firmware OEM original de la K10 (respaldo de fabrica)
    Localizado el firmware de fabrica publicado por palmarci (from_oem/p10_printer.bin),
    verificado autentico contra su dump de flash (byte a byte) y que cabe en el CBT6 de
    128KB. Binarios propietarios NO versionados (.gitignore); se deja README con fuente,
    hashes y procedimiento de restauracion por SD.
2026-06-14 docs: parametros K10 extraidos del firmware OEM (steps, PID, botones, pines acotados)
    - steps/mm X606 Y606 Z600 E1040, corrientes, feedrates, jerk, dims 100^3 (de k10_cfg.txt)
    - PID hotend Kp22.2/Ki1.08/Kd114, min_extrude 170, maxtemp 275, homing X-/Y+/Z-
    - acciones de botones S3-S9 con su G-code (retract/feed/print/posiciones)
    - pines acotados a PA/PB/PC + ADC1 + TIM1/3/4 + 4x HR4988 (mapeo fino pendiente)
2026-06-14 docs: mapa de pines K10 por reversing multi-agente (38 agentes)
    Alta confianza: PA2=termistor(ADC1_IN2), PA3=endstop, PA5/6/7=SPI1(display/SD),
    keypad 7 botones en PB0/1/10/12/13/14/15, PWM en PB4/5(TIM3) y PB6/7/8(TIM4).
    Media: STEP{PC15,PC13,PA9,PA11}/DIR{PC14,PA8,PA10,PA12}/EN{PB3,PA1} (eje sin resolver).
    Sin resolver: pin del HEATER (soft-PWM via tabla RAM). Alerta: OEM usa PA11/PA12 como
    stepper pero en esta placa son el USB Klipper (variante RCT6 vs CBT6).
2026-06-14 firmware: config Klipper para CNC (ATmega328P @16MHz, sin features opcionales)
    CNC Shield V3 + Arduino Uno. Desactivadas todas las WANT_ (SPI/I2C/ADC/PWM/sensores/
    displays) para caber en 32KB: resultado 12.7KB flash / 398B RAM. Solo step/dir/enable +
    endstops (core). Serial 250000 por USB de la Uno; flasheo avrdude/Optiboot.
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2026-06-17 docs: calibracion GRBL eje Z + motores STP-42D221 (200 pasos)
    Motores STP-42D221-01 = 200 pasos/rev (no 48). Z calibrado: $102=2225.8, dir invertida
    ($3=4), avance tornillo ~1.44mm/vuelta (no 2), backlash ~0.55mm, Vref 0.71V evita perdida
    de pasos. X/Y arranque corregido a 78.4 (200 pasos, polea O13mm), pendiente calibrar.
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2026-06-17 docs: respaldo de settings GRBL calibrados del CNC (verificado 0.02mm)
    CNC completamente calibrado y verificado: error de resolucion 0.02mm (<0.5% objetivo).
    Respaldo de $$ por si la EEPROM se reinicia (re-aplicar con estos valores).
    [grbl-settings-backup.txt]
